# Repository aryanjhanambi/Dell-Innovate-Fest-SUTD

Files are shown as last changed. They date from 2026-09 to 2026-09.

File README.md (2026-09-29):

# Yoda

A voice-first care necklace for elderly people living alone. She talks to it. It talks to her caregiver.

**[Demo video](https://www.youtube.com/watch?v=fLG9y0mhrLA)** · Top 5 Finalist, Dell InnovateDash 2026 (Care Corner)

> The wake word is "Jarvis". Espressif only ships a handful of pre-trained wake words and "Yoda" isn't one of them, so the repo kept the original name.

## Why

Singapore's community care services do exist. They are just scattered across portals, hotlines and 20-question intake forms, and the people who need them most are the least likely to get through an app to reach them. Someone who can talk to a necklace does not have to navigate any of that, and her caregiver still makes every decision.

## What it does

**Daily check-in.** The necklace starts a short recovery check-in on its own, tailored to what's on her record. Did you take your heart medicine. How's the cut on your chest. Any tightness or trouble breathing. Her answers become a health incident, and the dashboard turns that into an SBAR clinical handover a caregiver or a paramedic can actually act on.

**Welfare escalation.** If a caregiver can't reach her at the door or by phone, they ping the necklace from the dashboard. It beeps and asks her to respond. Only if she doesn't answer does the camera unlock, and only after the necklace has said out loud that it's turning on.

One rule underneath both: **the AI never acts alone.** Every action it wants to take becomes a request a human approves first.

## Architecture

```mermaid
flowchart LR
  Senior([Senior]) -->|voice| Pendant[Necklace<br/>XIAO ESP32-S3<br/>· firmware/ ·]
  Pendant -->|audio, MQTT+UDP| Cloud[xiaozhi.me<br/>ASR · LLM · TTS]
  Cloud <-->|MCP tool calls| Server[MCP server<br/>· repo root ·]
  Server --> Neon[(Neon Postgres)]
  Dash[Caregiver dashboard<br/>· dashboard/ ·] <--> Neon
  Dash -->|synthesize SBAR| LLM2[OpenAI]
  Pendant <-.->|poll for ping/camera<br/>push JPEG frames| Dash
  Caregiver([Caregiver]) --> Dash
```

The cloud LLM is the only thing that calls the tools. The dashboard and the MCP server never talk to each other directly, they meet at the database.

## The parts that were actually hard

**The MCP server dials out.** A hosted LLM can't reach a tool server sitting on a laptop behind NAT. So `mcp_pipe.py` opens the WebSocket in the other direction, to the cloud's MCP endpoint, and pipes it to a local stdio FastMCP process. No port forwarding, no public IP, no tunnel service.

**The emergency watchdog is a SQL expression, not a worker.** If she starts a health check and then goes quiet, that silence has to become an alert. Instead of a cron job or a background queue, the escalation is derived at query time:

```sql
CASE WHEN status = 'in_progress' AND now() - started_at > make_interval(secs => 25)
     THEN 'emergency' ...
```

The dashboard already polls every 3s, so the escalation just appears. Nothing to schedule, nothing to keep alive, nothing to crash silently.

**Seeing her from anywhere, with zero setup.** The first version needed the caregiver on the same Wi-Fi to reach the necklace's LAN server. Useless in practice. Now the necklace polls the dashboard for commands and pushes JPEG frames up over HTTPS, so everything is outbound. Works on a mobile hotspot, no router config.

**That relay was quietly killing the wake word.** After adding the relay, "Jarvis" stopped triggering. The cause was a fresh TLS handshake every 2 seconds hogging the CPU and starving the on-chip wake-word detector, which needs a steady mic feed. Throttling the idle poll to 15s brought it back. The camera stream still starves it while running, which is fine, that path is caregiver-initiated.

**Privacy is enforced on the device, not the dashboard.** The camera can't be turned on cold. It only unlocks after a ping goes unanswered, and the necklace speaks an announcement before the lens opens.

## What's real and what's mocked

Real: the voice loop, the tool calls, the database, the triage and escalation, the SBAR report, the camera relay, the firmware.

Mocked: the service providers. No Singapore community-care provider (Care Corner, AIC/ICCP, Meals-on-Wheels) exposes a public booking API, it's all phone, email and referral forms. The tools return realistic results and `services.py` keeps a one-function seam to drop in a real `httpx` call the day an API exists.

Also worth saying plainly: the firmware is a custom board overlay on [`78/xiaozhi-esp32`](https://github.com/78/xiaozhi-esp32) (MIT), not a from-scratch stack. The board definition, welfare HTTP API, cloud relay and camera path are mine.

## Repo layout

```
yoda-mcp/
├── yoda_iccp.py          # the 8 tools the cloud LLM can call
├── mcp_pipe.py           # dials OUT to the cloud MCP endpoint
├── health_db.py          # triage + the no-response escalation
├── kb_store.py           # senior profile load/merge (Neon or local file)
├── events.py             # activity matching
├── services.py           # mock provider adapter (the real-API seam)
├── SYSTEM_PROMPT.md      # the agent prompt, pasted into the xiaozhi console
├── test_*.py             # 14 tests
│
├── firmware/yoda-pendant/    # board overlay: config, welfare HTTP API, cloud relay
├── dashboard/                # Next.js caregiver dashboard
│   ├── app/                  # care view, welfare panel, SBAR report page
│   └── lib/                  # Neon queries + OpenAI report synthesis
└── cad/pendant_case.py       # parametric enclosure (build123d) -> printable STL
```

## The tools

| Tool | What it does |
|---|---|
| `get_senior_profile` | Recall who it's talking to. Called first, so it never re-asks what's on file. |
| `begin_health_check` | Open an incident the moment she reports feeling unwell. Starts the silence timer. |
| `complete_health_check` | File the triage with clinical red flags → `mild` / `serious` |
| `match_events` | Top 1-2 activities for her goals and area, excluding ones already requested |
| `request_activity` | Create a **pending request** for the caregiver. Never books directly. |
| `update_knowledge_base` | Save preferences learned in conversation |
| `get_onboarding_questions` | Short sign-up questions, only what isn't already known |
| `book_meal_delivery` | Mock meal booking |

## Run it

**MCP server** (repo root)

```bash
python -m venv .venv && .venv\Scripts\activate
pip install -r requirements.txt
# .env:  MCP_ENDPOINT=wss://api.xiaozhi.me/mcp/?token=...
#        DATABASE_URL=postgresql://...
python mcp_pipe.py yoda_iccp.py
```

Then paste `SYSTEM_PROMPT.md` into the xiaozhi.me console as the agent's role and hit Refresh on the MCP endpoint. Run only one MCP server at a time.

**Dashboard**

```bash
cd dashboard && npm install
# .env.local:  DATABASE_URL=...  OPENAI_API_KEY=...
npm run dev
```

**Tests**

```bash
pytest          # 14 tests: matching, KB merge, services, triage + escalation
```

## Security

`MCP_ENDPOINT`, `DATABASE_URL` and `OPENAI_API_KEY` live in `.env` / `.env.local`, both gitignored and never committed. The device token in `firmware/yoda-pendant/config.h` is a placeholder in this repo. Rotate the MCP token from the console if it ever leaks.

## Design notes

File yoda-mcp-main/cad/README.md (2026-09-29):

# Pendant case (XIAO ESP32-S3 Sense)

Parametric enclosure, printed in two parts. Every dimension is a number at the top of
`pendant_case.py`, so a bad test fit is a one-line change and a re-run, not a CAD session.

## Files

`pendant_case.py` is the model. It writes `pendant_base` and `pendant_lid` as both `.stl`
(slice these) and `.step` (edit these). `viewer.html` is a three.js preview, `preview.png`
is a static render.

## Regenerate

```bash
cd yoda-mcp
cad/.venv/Scripts/python.exe cad/pendant_case.py
```

Exports are vertex-merged and watertight-checked on the way out. A non-manifold edge fails
loudly here instead of halfway through a slicer.

## Preview in a browser

```bash
cd yoda-mcp/cad
.venv/Scripts/python.exe -m http.server 8000
# open http://localhost:8000/viewer.html
```

## What it holds

Interior 26 x 36 x 26 mm, outer 30 x 31 x 40 mm. That fits the XIAO ESP32-S3 Sense stack
(21 x 17.8 x 15), a 30 x 20 x 4.2 speaker, and a MAX98357 amp, stacked front to back.

The lid closes on a mid-wall spigot lip plus two diagonal M2 screws. The lip sits in the
middle of the wall rather than flush with the cavity, which keeps it clear of the screw
bosses and avoids the coincident faces that produce non-manifold geometry.

Camera hole is 7 mm (6 mm lens plus clearance), placed high so it clears the lanyard boss.
Three 2 mm holes below it vent the speaker and double as the mic opening. USB-C exits the
bottom edge.

## Printing

PLA, 0.2 mm layers, 3 walls, 15% infill. No supports needed: print the tub open side up and
the lid face down. Two M2 self-tapping screws, 6 to 8 mm.

## Tuning after a test fit

| Symptom | Parameter |
|---|---|
| Board will not drop in, or rattles | `BAYS["compact"]`, `WALL` |
| Camera hole misaligned | `CAM_OFF_X` (right is +), `CAM_OFF_Z` (up is +) |
| USB-C will not seat | `USB_OFF_X`, `USB_OFF_Y`, `USB_W`, `USB_H` |
| Lid too tight or too loose | `GROOVE_CLR` |
| Screws bind | `SCREW_CLEAR`, `SCREW_PILOT` |

`LAYOUT = "breadboard"` swaps in a larger bay if the amp is on a breadboard instead of
soldered.

## Known gaps

No board-retention ledge yet, the closed lid holds the board down. No dedicated antenna
channel either, the flat u.FL antenna tucks against an inside wall. Both are fine at this
size and worth adding once a print confirms the fit.

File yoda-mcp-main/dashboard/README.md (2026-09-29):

# Caregiver dashboard

The caregiver side. A live view of one senior that shows what the necklace found, and holds the
approval gate the agent cannot cross on its own.

Two screens.

**Care.** Health alerts as they come in. Each one carries the relevant slice of her care record
(diagnoses, medications, recent falls, pain) next to what she just reported, so the caregiver reads
the incident in context instead of as a bare notification. Anything serious gets an AI-synthesized
**SBAR clinical handover** at `/report/[id]`, formatted to print and hand to a paramedic. Pending
activity requests also land here for approve or decline.

**Welfare.** Ping the necklace, and only if she does not answer does the camera unlock. The
necklace announces itself out loud before the lens opens. Every action is written to a session log.

The page polls Neon every 3 seconds, which is also how the no-response emergency surfaces: the
escalation is a SQL expression evaluated at query time, not a background worker.

## Run

```bash
npm install
cp .env.example .env.local     # DATABASE_URL, OPENAI_API_KEY, DEVICE_TOKEN
npm run dev                    # http://localhost:3000
```

Same Neon database the MCP server writes to. The two never talk to each other directly.

## Key files

```
app/care-dashboard.tsx           # live UI, SWR poll
app/components/alerts-panel.tsx  # health alerts + inline report summary
app/welfare/welfare-panel.tsx    # ping, then camera on no-response
app/report/[id]/                 # printable SBAR handover

app/api/profile/route.ts         # GET  profile + requests + incidents
app/api/requests/route.ts        # POST approve / decline
app/api/alerts/route.ts          # POST acknowledge / resolve
app/api/report/[id]/route.ts     # POST synthesize, or return the cached report
app/api/welfare/route.ts         # POST ping / camera_on / camera_off
app/api/device/poll/route.ts     # the necklace asks for pending commands
app/api/device/frame/route.ts    # the necklace pushes a JPEG frame

lib/db.ts                        # Neon queries
lib/openai.ts                    # SBAR synthesis, server-only
```

Device routes are authenticated with a shared `DEVICE_TOKEN`, so only the necklace can poll for
commands or upload frames.

Stack: Next.js (App Router), Tailwind v4, `@neondatabase/serverless`, SWR. See the
[root README](../README.md) for the full architecture.

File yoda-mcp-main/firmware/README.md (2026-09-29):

# Pendant firmware

A XIAO ESP32-S3 Sense running the [xiaozhi-esp32](https://github.com/78/xiaozhi-esp32) voice
stack, plus a custom board (`yoda-pendant`) that adds the caregiver welfare check.

This folder is an **overlay, not a full firmware tree**. Upstream is ~18k files of MIT code, and
vendoring it here would bury the part that is actually ours. So this holds only our files, applied
onto a clean upstream checkout.

## What's ours

| Path | What it is |
|---|---|
| `yoda-pendant/config.h` | Pin map: I2S speaker (MAX98357A), PDM mic, camera, boot button, cloud relay config |
| `yoda-pendant/config.json` | Build target and sdkconfig (8 MB flash, EN_US, "Jarvis" wake word) |
| `yoda-pendant/yoda_pendant_board.cc` | The board: voice stack, LAN HTTP server, and the cloud relay loop |
| `assets/checking.ogg` | "We're checking on you now" privacy announce, played before the camera arms |
| `assets/door.ogg` | Legacy ping announce |
| `patches/esp32_camera.{h,cc}.patch` | Adds `CaptureToJpeg` and a lean `CaptureJpegStream` for MJPEG |
| `patches/CMakeLists.txt.patch` | Registers `BOARD_TYPE_YODA_PENDANT` |
| `patches/Kconfig.projbuild.patch` | Adds the board to the menuconfig list |
| `scripts/` | Build, flash and serial helpers (Windows) |

## Hardware

XIAO ESP32-S3 Sense: onboard camera (OV2640 or OV3660 depending on the batch, same Seeed pinout),
onboard PDM mic, 2.4 GHz WiFi, USB-CDC.

**MAX98357A I2S amp.** Note the silk labels on the XIAO are not GPIO numbers:

| Amp pin | GPIO | XIAO pad | Notes |
|---|---|---|---|
| LRC / WS | 1 | D0 | |
| BCLK | 2 | D1 | |
| DIN | 3 | D2 | |
| VIN | | 3V3 | |
| GND | | GND | must share ground with the XIAO |
| SD | | *(see below)* | shutdown + channel select, not optional |
| GAIN | | *(leave floating)* | floating gives the default gain |

These three GPIOs are the ones the board actually drives, so they have to match however the amp is
physically wired. If you rewire it, change `config.h` to suit, not the other way round.

**The SD pin is the one that bites you.** It is not just an on/off pin, it also picks the channel, and
the chip reads it as an analog voltage:

- Near 0 V (below ~0.16 V) the amp is in **full shutdown**. I2S keeps streaming, the ESP32 logs look
  perfect, and the speaker is completely silent. This is the classic false alarm: it looks like a
  software bug and it is not.
- Above roughly 1.4 V it plays the **left** channel. Mid voltages select right or a L+R mix.

Most of these breakouts have a pull-up so SD floats high on its own. Do not assume it. If there is any
doubt, jumper **SD to VIN** and the amp is forced awake on the left channel. The firmware sends the
same mono audio on both slots (`I2S_STD_SLOT_BOTH` in `yoda_pendant_board.cc`), so whichever channel
SD selects, there is audio in it.

**Speaker wiring.** The speaker's two wires go under the screws of the green terminal. If your speaker
came with a JST plug on the end, that plug does **not** mate with a screw terminal. Cut it off, strip
the wires, and clamp bare copper under the screws. A plug resting against the terminal reads as
"connected" by eye and passes no current.

PDM mic is on GPIO 42 (clock) and 41 (data). Wake word is "Jarvis", the stock WakeNet
`wn9_jarvis_tts` model. "Yoda" would need Espressif's paid custom training.

### Silent speaker, healthy logs

If the serial log reaches `State: speaking` and prints `<< ...` lines with no `EspUdp` or `MQTT`
errors, the whole software path is fine: mic, ASR, LLM, TTS and audio transport all worked. That says
nothing about which physical pins the audio is leaving on, or what happens after the amp. Work down
this list, in order:

1. **Pin map mismatch.** The three GPIOs above must match how the amp is actually wired. If they
   don't, the chip clocks I2S out of pins with nothing attached and every log line still looks
   perfect. Check this before touching the hardware.
2. **SD pin** at 0 V or floating low, so the amp is shut down (see above).
3. **Speaker not actually clamped** in the screw terminal (see above).
4. **Ground not common** between amp and XIAO.
5. **No power on VIN.**
6. **Blown speaker.** A 1 W driver run at high volume dies quickly, so keep the volume low while
   testing.

A useful splitter: with the amp powered, briefly tap the `DIN` pin to 3.3 V and back. A live amp and a
live speaker will click or pop audibly. Clicks mean the analog side is fine and the problem is
upstream. No clicks at all means the amp is asleep, unpowered, or not connected to the speaker.

## Two ways the caregiver reaches the necklace

**Cloud relay (the one that matters).** The necklace polls the deployed dashboard for pending
commands and pushes JPEG frames back up, both outbound over HTTPS. No port forwarding, no LAN
discovery, no public IP. It works on a mobile hotspot. Configured by `YODA_CLOUD_BASE` /
`YODA_DEVICE_TOKEN` in `config.h`, hitting `/api/device/poll` and `/api/device/frame`.

The idle poll is deliberately slow (15 s). A faster poll means a fresh TLS handshake every cycle,
which starves the on-chip wake-word detector of CPU and stops "Jarvis" triggering at all. That bug
cost a while to find, so the interval is load-bearing, not arbitrary.

**LAN HTTP server (fallback).** Kept for same-WiFi debugging.

| Endpoint | Effect |
|---|---|
| `GET /ping` | Beep and announce, asking her to respond |
| `GET /camera/on` | Privacy announce, then arm the camera |
| `GET /capture` | One JPEG still, only when armed |
| `GET /stream` | Live MJPEG until the client disconnects |
| `GET /camera/off` | Disarm, stream loop exits |

Camera frames are gated behind `/camera/on` by design. The caregiver cannot see anything until the
necklace has said out loud that it is turning on.

## Build from scratch

Needs ESP-IDF v5.5.x (built against 5.5.2).

```powershell
git clone https://github.com/78/xiaozhi-esp32.git
cd xiaozhi-esp32
powershell -File ..\yoda-mcp\firmware\apply-overlay.ps1 -XiaozhiRoot .
python scripts\release.py yoda-pendant
```

The wake word and 8 MB flash config come from `config.json`'s `sdkconfig_append`, so a clean build
is already set to Jarvis with no manual menuconfig.

```powershell
idf.py -p COM5 flash        # COM5 is single-access, close any serial monitor first
pio device monitor -p COM5 -b 115200
```

On boot the log prints the device's LAN IP for the fallback path:
`=== JARVIS WELFARE: device IP = 10.x.x.x ===`

> The `scripts/*.bat` helpers hard-code local paths (ESP-IDF under `C:\Users\...`). They are
> committed as a record of how this machine builds. Edit the paths for another environment, or use
> the raw `idf.py` commands above.

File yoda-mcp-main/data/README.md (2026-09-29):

# Demo data

`profiles/mdm-tan.json` is **synthetic**. "Madam Tan" is a fictional person invented
for the demo. Nothing here is real patient data.

The shape follows interRAI-style assessment sections (cognition, mood, functional
status, health conditions, medications) because that is the format Singapore
community-care providers actually assess with, so the agent is built against a
realistic record rather than a toy `{name, age}` object.

It is used two ways:

- `KB_BACKEND=local` reads these files directly, which lets the whole system run
  with no database.
- `KB_BACKEND=neon` reads the same shape from Postgres, and this file is the seed.

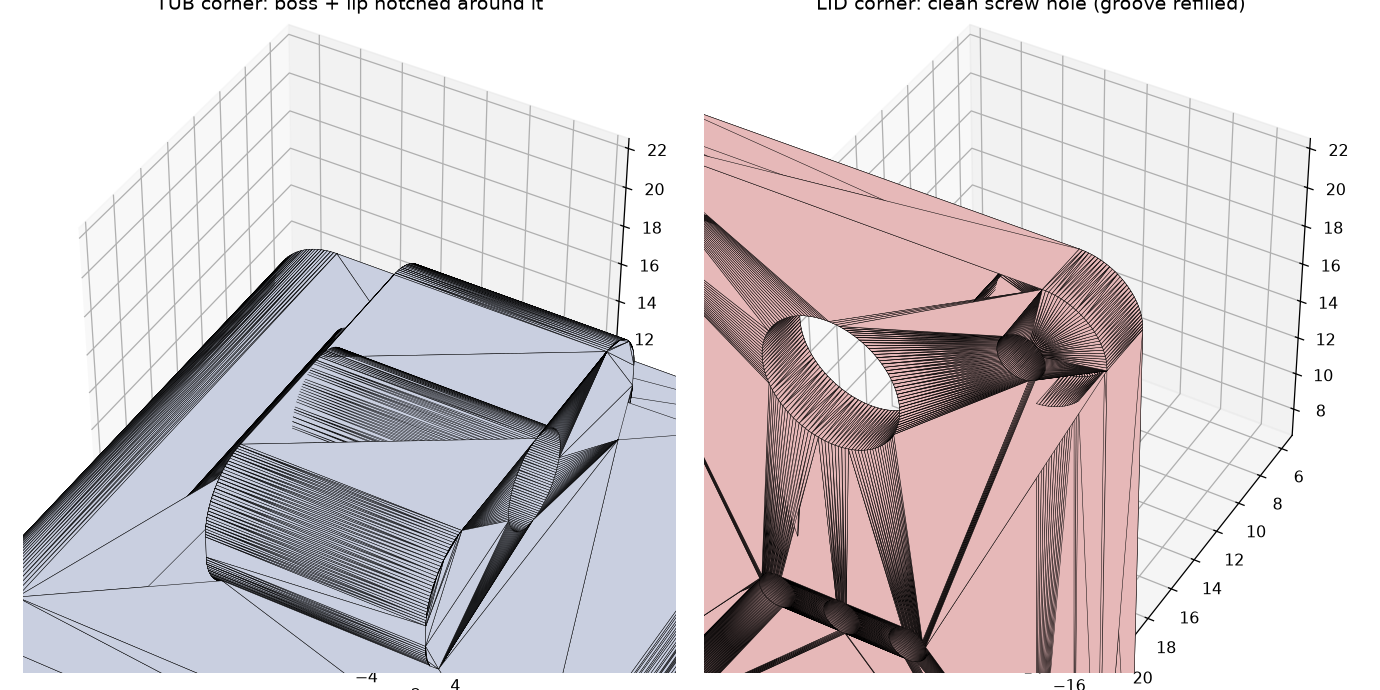
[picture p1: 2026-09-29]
yoda-mcp-main/cad/preview.png

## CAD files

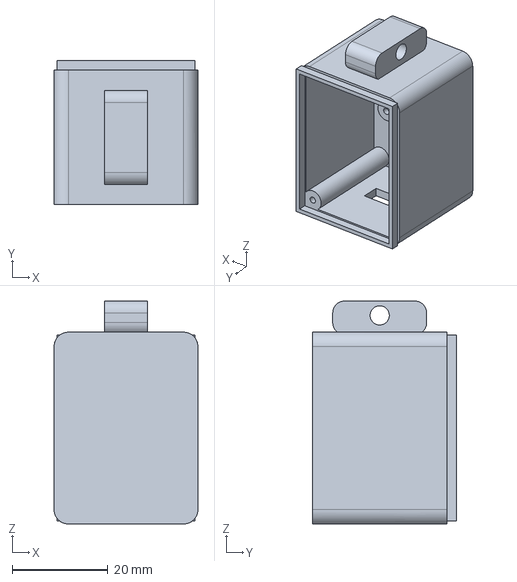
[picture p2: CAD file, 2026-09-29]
yoda-mcp-main/cad/pendant_base.step
30.0 x 30.0 x 46.5 mm

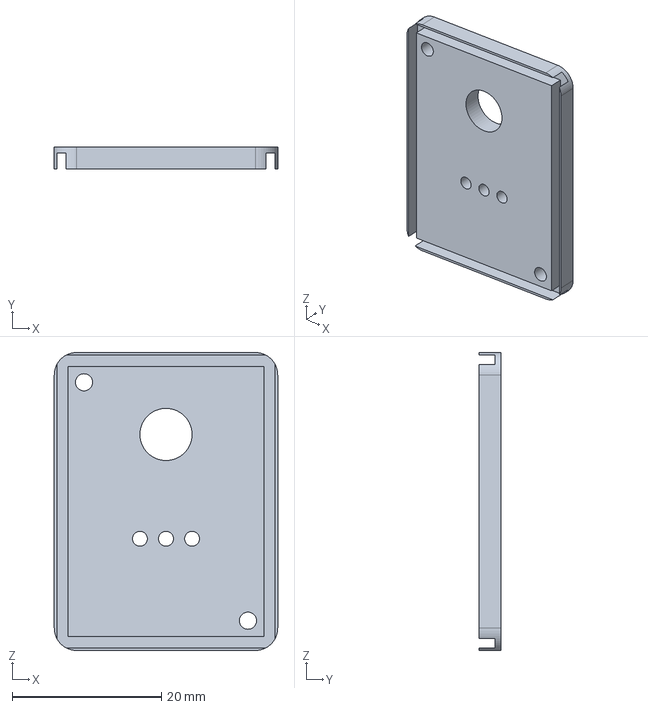
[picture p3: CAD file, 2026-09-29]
yoda-mcp-main/cad/pendant_lid.step
30.0 x 3.00 x 40.0 mm

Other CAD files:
yoda-mcp-main/cad/pendant_base.stl
yoda-mcp-main/cad/pendant_lid.stl

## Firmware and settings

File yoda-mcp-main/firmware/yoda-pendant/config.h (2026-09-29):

#ifndef _BOARD_CONFIG_H_
#define _BOARD_CONFIG_H_

#include <driver/gpio.h>

// ===================== Yoda Pendant =====================
// Seeed XIAO ESP32-S3 Sense + MAX98357A amplifier + onboard PDM mic + OV2640 camera.
// No display, no LED (base Board provides NoDisplay / NoLed).

// ---------------- Audio ----------------
// Speaker: MAX98357A (I2S standard output).  Mic: onboard PDM microphone.
// Driven by NoAudioCodecSimplexPdm (separate speaker I2S + PDM mic RX).
#define AUDIO_INPUT_SAMPLE_RATE  16000
#define AUDIO_OUTPUT_SAMPLE_RATE 24000

// I2S amplifier. Silk D-labels are not GPIO numbers: GPIO1=D0, GPIO2=D1, GPIO3=D2.
// amp LRC->GPIO1, amp BCLK->GPIO2, amp DIN->GPIO3, VIN->3.3V, GND->GND.
// These must match how the amp is physically wired; if you rewire, update these.
#define AUDIO_I2S_SPK_GPIO_LRCK  GPIO_NUM_1   // LRC/WS on the amp -> GPIO1 (pad D0)
#define AUDIO_I2S_SPK_GPIO_BCLK  GPIO_NUM_2   // BCLK on the amp   -> GPIO2 (pad D1)
#define AUDIO_I2S_SPK_GPIO_DOUT  GPIO_NUM_3   // DIN on the amp    -> GPIO3 (pad D2)

// Onboard PDM microphone (XIAO ESP32-S3 Sense daughterboard)
#define AUDIO_I2S_MIC_GPIO_CLK   GPIO_NUM_42  // PDM clock
#define AUDIO_I2S_MIC_GPIO_DIN   GPIO_NUM_41  // PDM data

// ---------------- Buttons ----------------
#define BOOT_BUTTON_GPIO         GPIO_NUM_0

// ---------------- Camera (OV2640 on XIAO ESP32-S3 Sense, Seeed pinout) ----------------
#define CAMERA_PIN_PWDN   GPIO_NUM_NC
#define CAMERA_PIN_RESET  GPIO_NUM_NC
#define CAMERA_PIN_XCLK   GPIO_NUM_10
#define CAMERA_PIN_SIOD   GPIO_NUM_40   // SCCB SDA
#define CAMERA_PIN_SIOC   GPIO_NUM_39   // SCCB SCL
#define CAMERA_PIN_D7     GPIO_NUM_48   // Y9
#define CAMERA_PIN_D6     GPIO_NUM_11   // Y8
#define CAMERA_PIN_D5     GPIO_NUM_12   // Y7
#define CAMERA_PIN_D4     GPIO_NUM_14   // Y6
#define CAMERA_PIN_D3     GPIO_NUM_16   // Y5
#define CAMERA_PIN_D2     GPIO_NUM_18   // Y4
#define CAMERA_PIN_D1     GPIO_NUM_17   // Y3
#define CAMERA_PIN_D0     GPIO_NUM_15   // Y2
#define CAMERA_PIN_VSYNC  GPIO_NUM_38
#define CAMERA_PIN_HREF   GPIO_NUM_47
#define CAMERA_PIN_PCLK   GPIO_NUM_13
#define XCLK_FREQ_HZ      20000000

// ---------------- Cloud relay (welfare from anywhere, no LAN IP) ----------------
// The necklace polls the deployed dashboard for ping/camera commands and pushes JPEG
// photos up, so the caregiver can check on the senior over the internet. The LAN HTTP
// server (yoda_pendant_board.cc) is kept as a same-Wi-Fi fallback.
#define YODA_CLOUD_BASE   "https://jarvis-care-dashboard.up.railway.app"
#define YODA_DEVICE_TOKEN "REPLACE_WITH_DEVICE_TOKEN_MATCHING_DASHBOARD_ENV"
#define YODA_SENIOR_ID    "mdm-tan"

#endif // _BOARD_CONFIG_H_

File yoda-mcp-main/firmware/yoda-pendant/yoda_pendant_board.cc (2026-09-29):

#include "wifi_board.h"
#include "codecs/no_audio_codec.h"
#include "system_reset.h"
#include "application.h"
#include "button.h"
#include "config.h"
#include "mcp_server.h"
#include "esp32_camera.h"

#include <esp_log.h>
#include <esp_http_server.h>
#include <esp_netif.h>
#include <esp_wifi.h>
#include <freertos/FreeRTOS.h>
#include <freertos/task.h>
#include <string>
#include <string_view>

#define TAG "JarvisPendant"

// Pre-rendered announce clips (Opus/OGG), embedded from assets/common/*.ogg.
extern const char door_ogg_start[] asm("_binary_door_ogg_start");
extern const char door_ogg_end[]   asm("_binary_door_ogg_end");
extern const char checking_ogg_start[] asm("_binary_checking_ogg_start");
extern const char checking_ogg_end[]   asm("_binary_checking_ogg_end");

// Shared with the HTTP handlers (the board is a singleton).
static Esp32Camera* s_camera = nullptr;
static volatile bool s_camera_armed = false;

// Yoda welfare-check necklace: XIAO ESP32-S3 Sense + MAX98357A speaker + onboard
// PDM mic + OV2640 camera. Runs the xiaozhi voice stack AND a tiny LAN HTTP server
// so the caregiver dashboard can ping the senior and pull a camera photo on demand.
class YodaPendant : public WifiBoard {
private:
    Button boot_button_;
    Esp32Camera* camera_;
    httpd_handle_t server_ = nullptr;

    void InitializeCamera() {
        camera_config_t config = {};
        config.pin_d0 = CAMERA_PIN_D0;
        config.pin_d1 = CAMERA_PIN_D1;
        config.pin_d2 = CAMERA_PIN_D2;
        config.pin_d3 = CAMERA_PIN_D3;
        config.pin_d4 = CAMERA_PIN_D4;
        config.pin_d5 = CAMERA_PIN_D5;
        config.pin_d6 = CAMERA_PIN_D6;
        config.pin_d7 = CAMERA_PIN_D7;
        config.pin_xclk = CAMERA_PIN_XCLK;
        config.pin_pclk = CAMERA_PIN_PCLK;
        config.pin_vsync = CAMERA_PIN_VSYNC;
        config.pin_href = CAMERA_PIN_HREF;
        config.pin_sccb_sda = CAMERA_PIN_SIOD;
        config.pin_sccb_scl = CAMERA_PIN_SIOC;
        config.sccb_i2c_port = 1;  // keep camera SCCB off I2C0
        config.pin_pwdn = CAMERA_PIN_PWDN;
        config.pin_reset = CAMERA_PIN_RESET;
        config.xclk_freq_hz = XCLK_FREQ_HZ;
        config.pixel_format = PIXFORMAT_RGB565;
        config.frame_size = FRAMESIZE_VGA;
        config.jpeg_quality = 12;
        config.fb_count = 2;  // double-buffer: grab next frame while encoding -> smoother stream
        config.fb_location = CAMERA_FB_IN_PSRAM;
        config.grab_mode = CAMERA_GRAB_WHEN_EMPTY;
        camera_ = new Esp32Camera(config);
        camera_->SetHMirror(false);
        camera_->SetVFlip(false);
        s_camera = camera_;
    }

    void InitializeButtons() {
        boot_button_.OnClick([this]() {
            auto& app = Application::GetInstance();
            if (app.GetDeviceState() == kDeviceStateStarting) {
                EnterWifiConfigMode();
                return;
            }
            app.ToggleChatState();
        });
    }

    // ---- Welfare-check HTTP server (reached directly by the caregiver dashboard over the LAN) ----

    static void AddCors(httpd_req_t* req) {
        httpd_resp_set_hdr(req, "Access-Control-Allow-Origin", "*");
    }

    // GET /ping  -> beep + "someone is at the door" announce
    static esp_err_t PingHandler(httpd_req_t* req) {
        AddCors(req);
        std::string_view checkin(checking_ogg_start, (size_t)(checking_ogg_end - checking_ogg_start));
        Application::GetInstance().PlaySound(checkin);
        ESP_LOGI(TAG, "/ping -> played check-in announce");
        httpd_resp_set_type(req, "application/json");
        httpd_resp_sendstr(req, "{\"ok\":true,\"action\":\"ping\"}");
        return ESP_OK;
    }

    // GET /camera/on -> privacy announce, then arm the camera
    static esp_err_t CameraOnHandler(httpd_req_t* req) {
        AddCors(req);
        std::string_view checking(checking_ogg_start, (size_t)(checking_ogg_end - checking_ogg_start));
        Application::GetInstance().PlaySound(checking);
        s_camera_armed = true;
        ESP_LOGI(TAG, "/camera/on -> announced + armed");
        httpd_resp_set_type(req, "application/json");
        httpd_resp_sendstr(req, "{\"ok\":true,\"action\":\"camera_on\"}");
        return ESP_OK;
    }

    // GET /camera/off -> disarm
    static esp_err_t CameraOffHandler(httpd_req_t* req) {
        AddCors(req);
        s_camera_armed = false;
        ESP_LOGI(TAG, "/camera/off -> disarmed");
        httpd_resp_set_type(req, "application/json");
        httpd_resp_sendstr(req, "{\"ok\":true,\"action\":\"camera_off\"}");
        return ESP_OK;
    }
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
